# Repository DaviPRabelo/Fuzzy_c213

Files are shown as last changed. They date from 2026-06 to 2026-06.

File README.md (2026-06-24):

<div align="center">

# Câmara Térmica — Controle Fuzzy

Controle de temperatura de uma câmara térmica por **lógica fuzzy (Mamdani)**,
com visualização em tempo real por um dashboard web via **MQTT**.







`C213 · Sistemas Embarcados · Inatel`

</div>

---

## Sumário

- [Arquitetura](#arquitetura)
- [Convenção de sinais](#convenção-de-sinais)
- [Estrutura de arquivos](#estrutura-de-arquivos)
- [Como rodar o controlador](#como-rodar-o-controlador)
- [Como abrir o dashboard](#como-abrir-o-dashboard)
- [Comunicação MQTT](#comunicação-mqtt)
- [Limitações conhecidas](#limitações-conhecidas)

## Integrantes

| Nome | Matrícula |
|---|---:|
| DAVÍ PADULA RABELO | 1917 |
| KAUÃ VICTOR GARCIA SIÉCOLA | 1887 |
| MATHEUS RENÓ TORRES | 1954 |
---

## Arquitetura

```mermaid
flowchart LR
    DASH["Dashboard<br/>(browser)"]
    BROKER(["Broker MQTT · HiveMQ"])
    ESP["ESP32 · controle fuzzy<br/>(pendente)"]
    PLANT["Aquecedor / Cooler<br/>+ sensor de temperatura"]

    DASH -->|setpoint| BROKER
    BROKER -->|setpoint| ESP
    ESP -->|telemetria JSON| BROKER
    BROKER -->|telemetria| DASH
    ESP -->|PWM| PLANT
    PLANT -->|temperatura| ESP

    classDef pending stroke-dasharray:5 5,fill:#fff7ed,stroke:#fb923c,color:#9a3412;
    class ESP pending;
```

O sistema tem três peças conceituais:

| Peça | Arquivo | Papel |
|---|---|---|
| Projeto do controlador | `fuzzy.py` | Define pertinências + 25 regras, valida e gera gráficos (roda no PC, **offline**) |
| Interface | `dashboard.html` | Mostra temperatura/setpoint/erro/ação em tempo real e envia o setpoint |
| Controle embarcado | *(pendente)* | Firmware do ESP32 que lê o sensor, roda o fuzzy, aciona PWM e publica MQTT |

> O `fuzzy.py` é uma ferramenta **offline**: projeta o controlador, imprime testes de
> sinal e gera os gráficos das pertinências e da superfície de controle.

---

## Convenção de sinais

Toda a lógica segue uma convenção única, consistente entre o `.py` e o dashboard:

| Grandeza | Definição | Interpretação |
|---|---|---|
| **erro** | `e = SP − T` | `e > 0` → está **frio** (T abaixo do setpoint) |
| **Δe** (delta_erro) | variação do erro entre amostras | tendência (esfriando / esquentando) |
| **u** (ação) | saída de controle em % | **`u > 0` → aquecer** · **`u < 0` → resfriar** |

Termos linguísticos: `NG` (negativo grande) … `ZE` (zero) … `PG` (positivo grande)
para as entradas; `RF` (resfriar forte) … `MA` (manter) … `AF` (aquecer forte) para a saída.

---

## Estrutura de arquivos

```
fuzzy_codigo/
├── fuzzy.py            # controlador fuzzy + geração de gráficos (offline)
├── dashboard.html      # painel web em tempo real (MQTT + Chart.js)
├── requirements.txt    # dependências Python
├── pertinencias.png    # gráfico das funções de pertinência (gerado pelo .py)
├── superficie.png      # superfície de controle 3D (gerado pelo .py)
└── README.md
```

---

## Como rodar o controlador

O controlador vive em `fuzzy.py`.

1. Crie um ambiente virtual e instale as dependências:

   ```bash
   python -m venv .venv
   # Windows
   .venv\Scripts\activate
   # Linux/macOS
   source .venv/bin/activate

   python -m pip install -r requirements.txt
   ```

2. Execute:

   ```bash
   python fuzzy.py
   ```

   O script imprime três testes de sinal e gera os dois gráficos:

   | Saída | O que mostra |
   |-------|--------------|
   | `pertinencias.png` | As funções de pertinência de **erro**, **Δe** e **ação** |
   | `superficie.png` | A **superfície de controle** 3D `u = f(erro, Δe)` |

---

## Como abrir o dashboard

O dashboard vive em `dashboard.html`.

> [!TIP]
> Sirva o arquivo por HTTP — alguns navegadores bloqueiam WebSocket a partir de `file://`.

```bash
python -m http.server 8080
# depois abra  http://localhost:8080/dashboard.html
```

O indicador de status mostra:

- 🔴 **Desconectado** — sem conexão com o broker (tenta reconectar a cada 3 s);
- 🟢 **Conectado** — recebendo telemetria normalmente;
- 🟡 **Conectado · sem dados** — conexão ativa, mas sem telemetria há mais de 8 s
  (ESP32 parou de publicar / sinal perdido).

Os botões de setpoint (35 / 50 / 65 °C) publicam o novo SP no broker.

### Painel "Inferência Fuzzy"

O dashboard reimplementa o controlador Mamdani em JavaScript (mesmas funções de
pertinência e as 25 regras de `fuzzy.py`) e mostra, em tempo real, o passo a
passo da inferência a cada amostra:

1. **Fuzzificação** — funções de pertinência de `erro` e `Δe` com o valor atual marcado
   e os termos ativos destacados;
2. **Base de regras** — a matriz 5×5; a célula destacada (com anel) é a regra dominante
   no instante, tingida pela intensidade de ativação μ;
3. **Defuzzificação** — o conjunto de saída agregado, o **centroide** e, em seguida, o
   **comando** após o ganho de saída `Ku` e a saturação em ±100 % (ver abaixo),
   atualizados junto com a telemetria.

### Saída do atuador (ganho Ku + saturação)

O centroide do conjunto agregado nunca alcança as bordas do universo — mesmo com `RF`/`AF`
totalmente ativados ele satura em ≈ ±79 %. Por isso o controlador aplica a estrutura padrão
**núcleo fuzzy → ganho de saída `Ku` ≈ 1,27 → saturação em ±100 %**, usando toda a faixa
física do atuador (`u>0` aquece, `u<0` resfria). O painel de defuzzificação mostra as duas
grandezas: o `centroide` (tracejado) e o `comando` final (linha cheia).

---

## Comunicação MQTT

| Item | Valor |
|---|---|
| Broker | `broker.hivemq.com` |
| Porta | `8000` (WebSocket) |
| Tópico de telemetria | `inatel/c213/camara/dados` — **ESP32 → dashboard** (JSON) |
| Tópico de setpoint | `inatel/c213/camara/setpoint` — **dashboard → ESP32** (número como texto, `retained`) |

**Formato do JSON em `inatel/c213/camara/dados`:**

```json
{ "temp": 31.4, "sp": 50, "erro": 18.6, "u": 73 }
```

| Campo | Tipo | Descrição |
|---|---|---|
| `temp` | número | temperatura medida (°C) |
| `sp` | número | setpoint atual (°C) |
| `erro` | número | `e = sp − temp` (°C) |
| `u` | número | ação de controle em % (`u>0` aquece, `u<0` resfria) |
| `de` | número *(opcional)* | variação do erro Δe; se ausente, o dashboard a deriva de amostras sucessivas |

O dashboard tolera campos ausentes e ignora payloads com JSON inválido ou campos
mal-tipados (validação numérica em cada campo).

---

## Limitações conhecidas

- **Broker público sem isolamento:** `broker.hivemq.com` é compartilhado e sem
  autenticação/TLS; os tópicos são fixos. Para uso em laboratório, prefira WSS
  (porta 8884) e prefixe os tópicos com um identificador único da equipe.

---

<div align="center">
<sub>C213 · Sistemas Embarcados · Inatel</sub>
</div>

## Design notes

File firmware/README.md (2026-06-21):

# Thermal Chamber Fuzzy ESP32

Firmware PlatformIO para controle fuzzy de uma câmara térmica usando ESP32, sensor BMP180 e ventoinha/exaustor acionado por PWM.

## Hardware considerado

- ESP32 comum (`board = esp32dev`)
- BMP180 via I2C
- Ventoinha acionada por PWM via transistor/MOSFET externo
- MQTT para setpoint e telemetria

## Pinagem

| Função | GPIO |
|---|---:|
| SDA BMP180 | GPIO5 |
| SCL BMP180 | GPIO4 |
| PWM ventoinha | GPIO2 |

Observação: GPIO2 é pino de strapping no ESP32. Funciona como PWM, mas o circuito externo não deve forçar nível indevido durante o boot.

## Tópicos MQTT

### Setpoint

```text
thermal_chamber/c3_01/setpoint
```

Payload aceito:

```json
45.0
```

ou:

```json
{"setpoint": 45.0}
```

### Telemetria

```text
thermal_chamber/c3_01/telemetry
```

Exemplo:

```json
{
  "device_id": "thermal-chamber-esp32-01",
  "temp_c": 47.35,
  "setpoint_c": 45.00,
  "error_c": 2.35,
  "delta_error_c": 0.18,
  "pwm_pct": 72.0,
  "sensor_ok": true,
  "safety_mode": false,
  "uptime_ms": 123456
}
```

### Status

```text
thermal_chamber/c3_01/status
```

## Configuração de rede

Copie:

```bash
cp include/secrets.example.h include/secrets.h
```

Edite `include/secrets.h` com sua rede Wi-Fi e broker MQTT.

Se `include/secrets.h` não existir, o projeto usa `secrets.example.h` apenas para permitir compilação inicial.

## Comandos

Compilar:

```bash
pio run -e esp32
```

Gravar:

```bash
pio run -e esp32 -t upload
```

Monitor serial:

```bash
pio device monitor
```

Testes do controlador fuzzy no PC:

```bash
pio test -e native
```

## Controle

O erro foi definido como:

```text
erro = temperatura_medida - setpoint
```

Assim, quando a temperatura está acima do setpoint, o erro é positivo e a ventoinha deve aumentar a exaustão.

Como o soprador térmico não é controlado pelo ESP32, a saída fuzzy controla apenas a capacidade de resfriamento/exaustão.

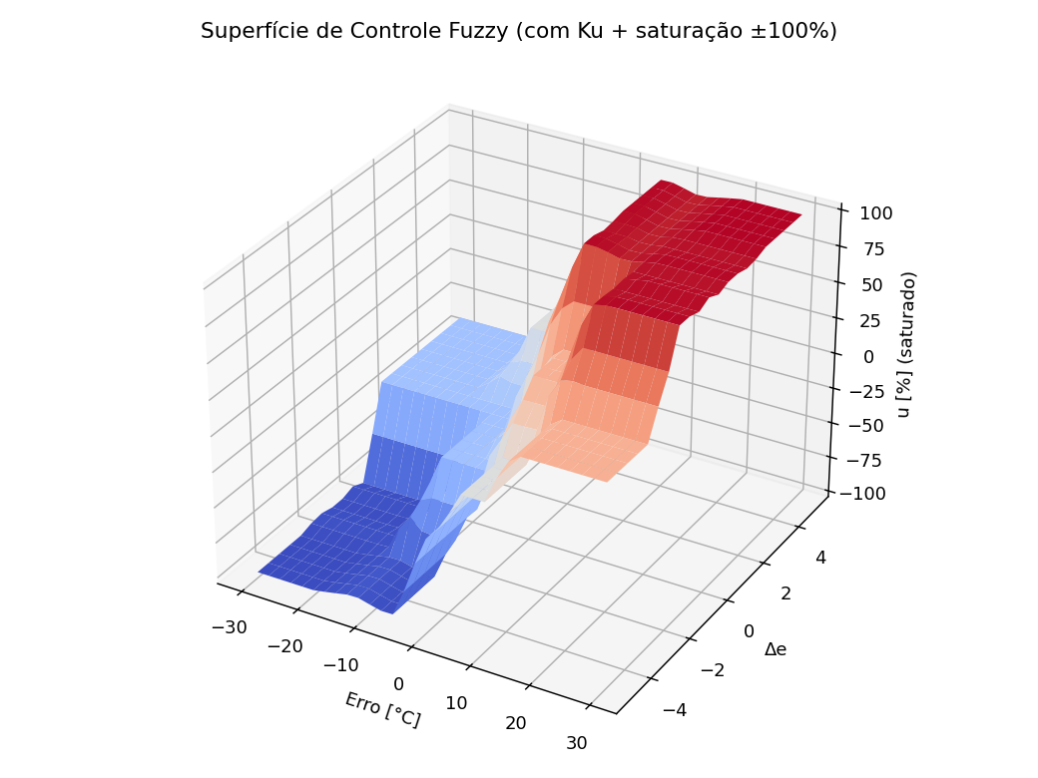
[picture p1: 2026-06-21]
superficie.png

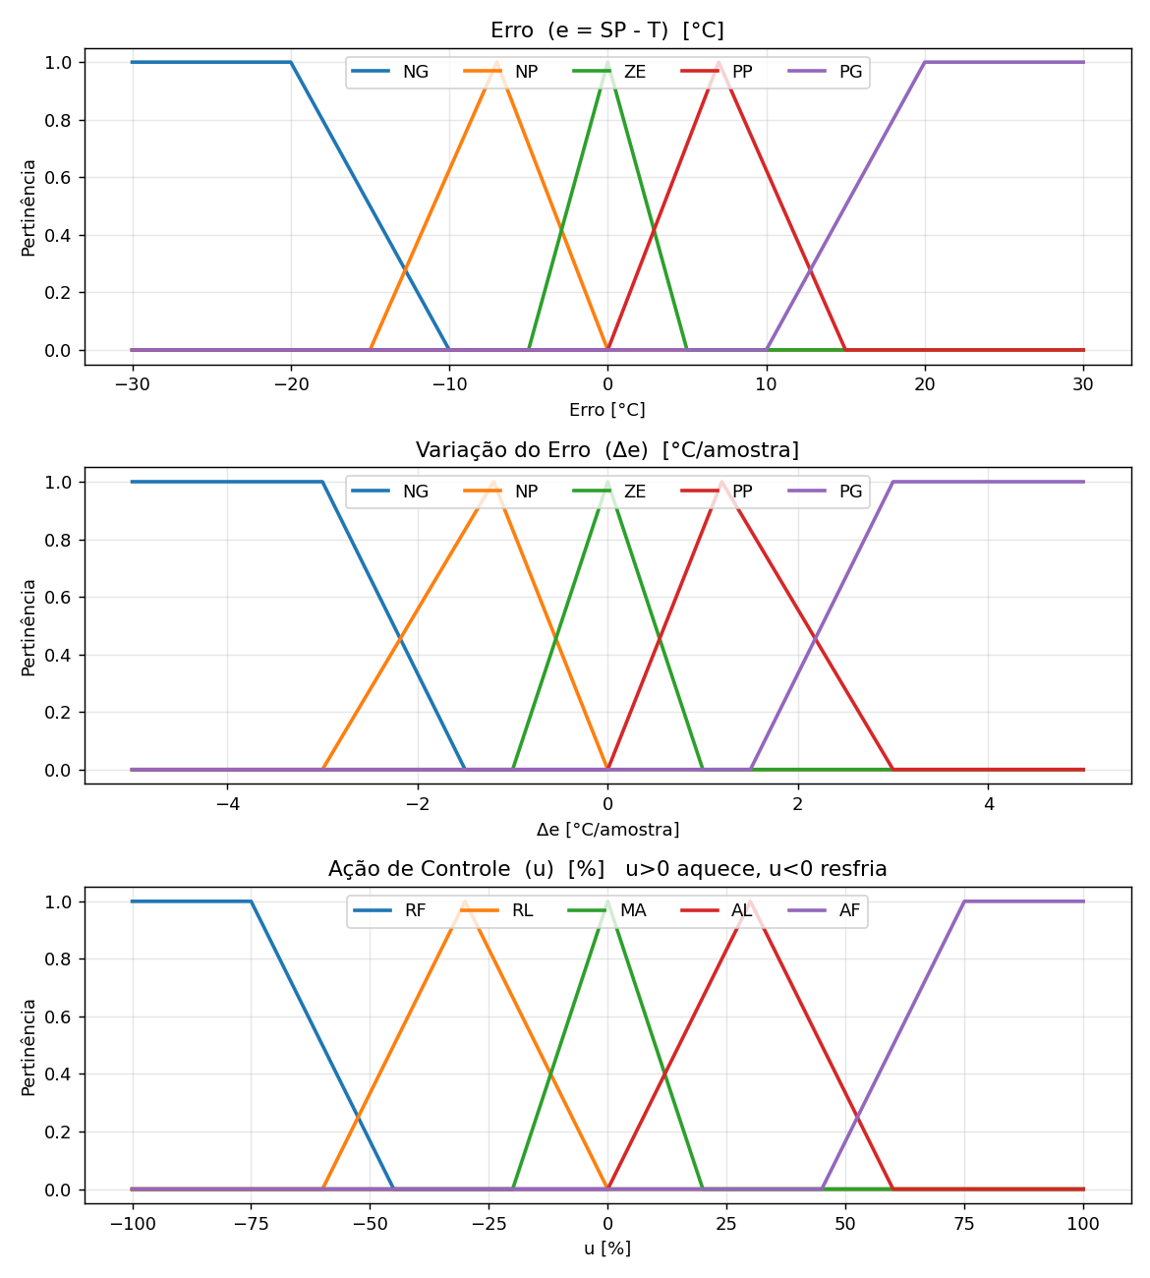
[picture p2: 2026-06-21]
pertinencias.png

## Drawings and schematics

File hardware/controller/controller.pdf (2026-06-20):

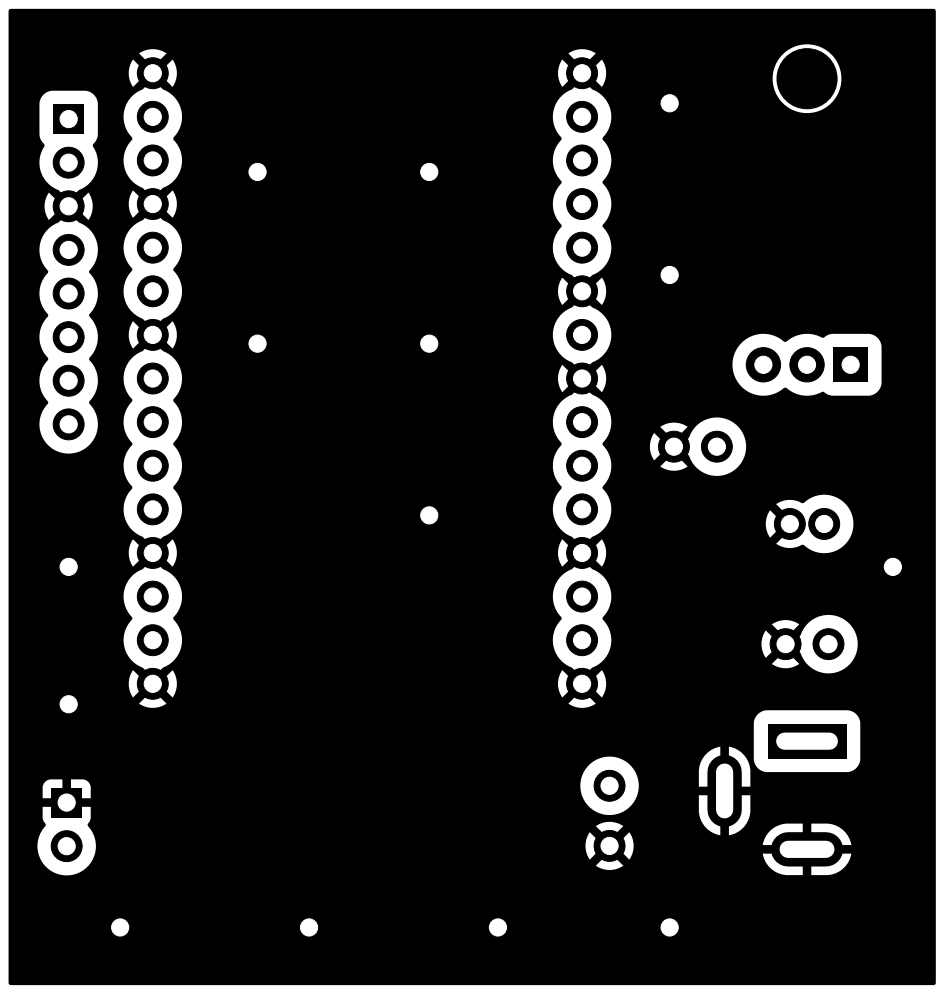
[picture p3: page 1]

Size: A4 | Rev:
KiCad E.D.A. 10.0.3 | Id: 1/2

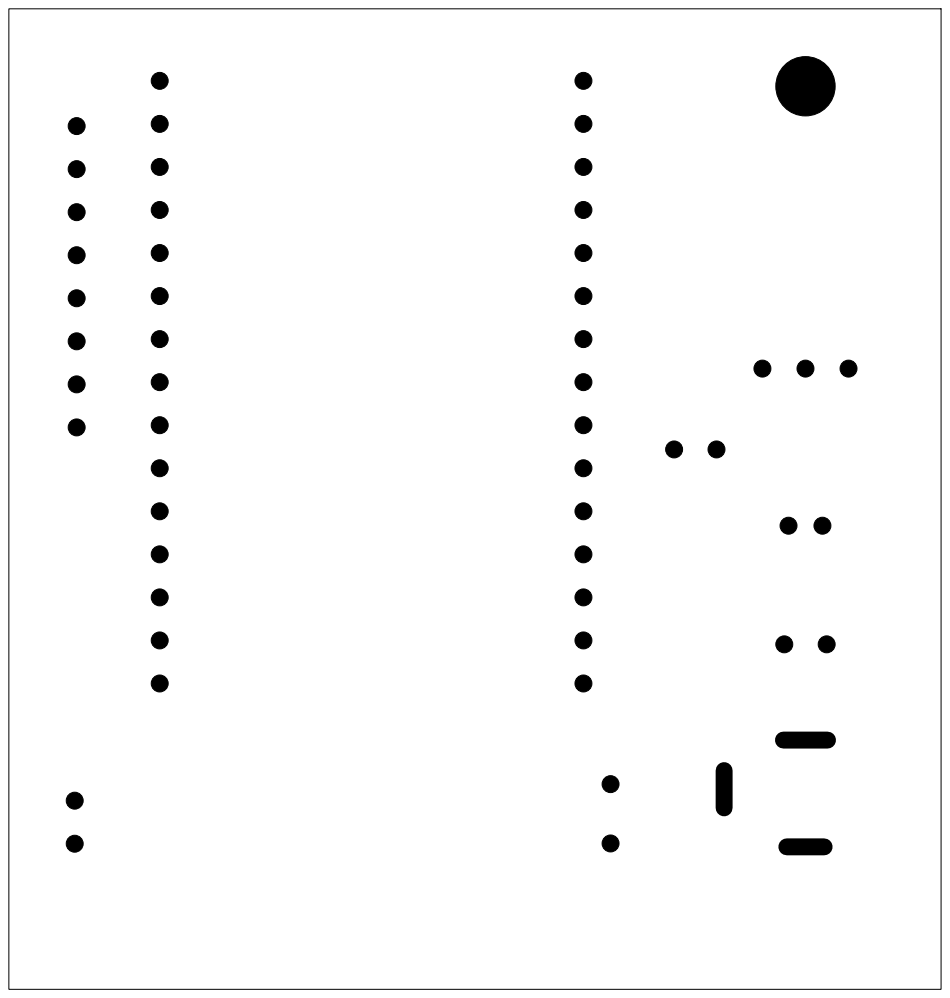
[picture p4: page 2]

Size: A4 | Rev:
KiCad E.D.A. 10.0.3 | Id: 2/2

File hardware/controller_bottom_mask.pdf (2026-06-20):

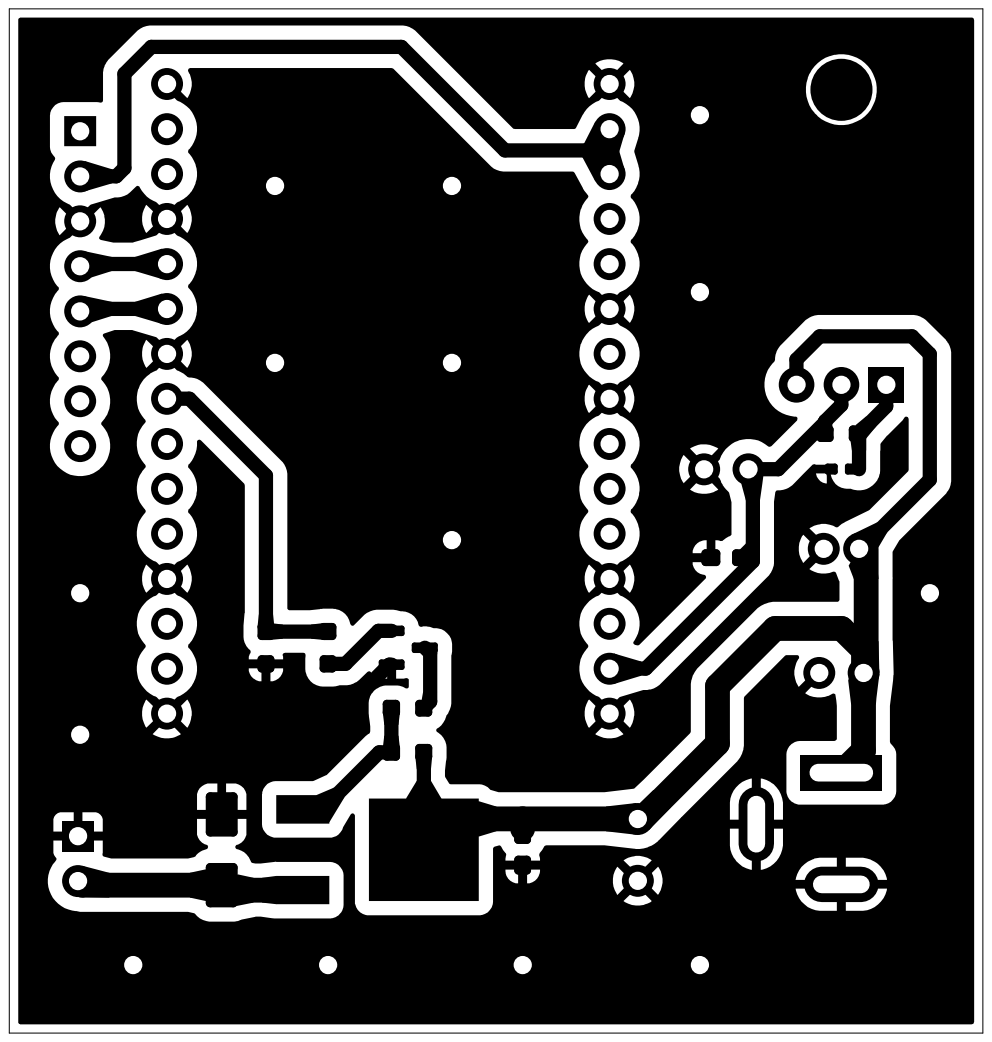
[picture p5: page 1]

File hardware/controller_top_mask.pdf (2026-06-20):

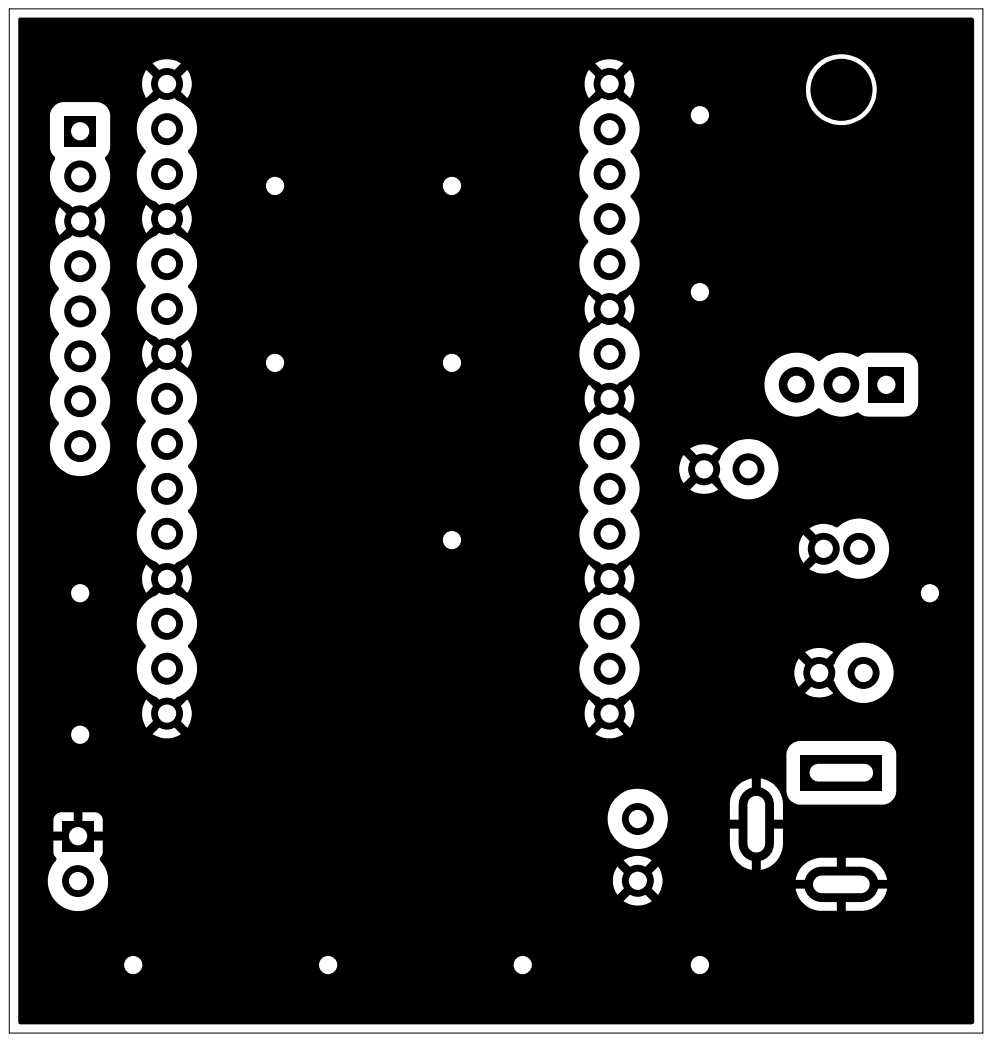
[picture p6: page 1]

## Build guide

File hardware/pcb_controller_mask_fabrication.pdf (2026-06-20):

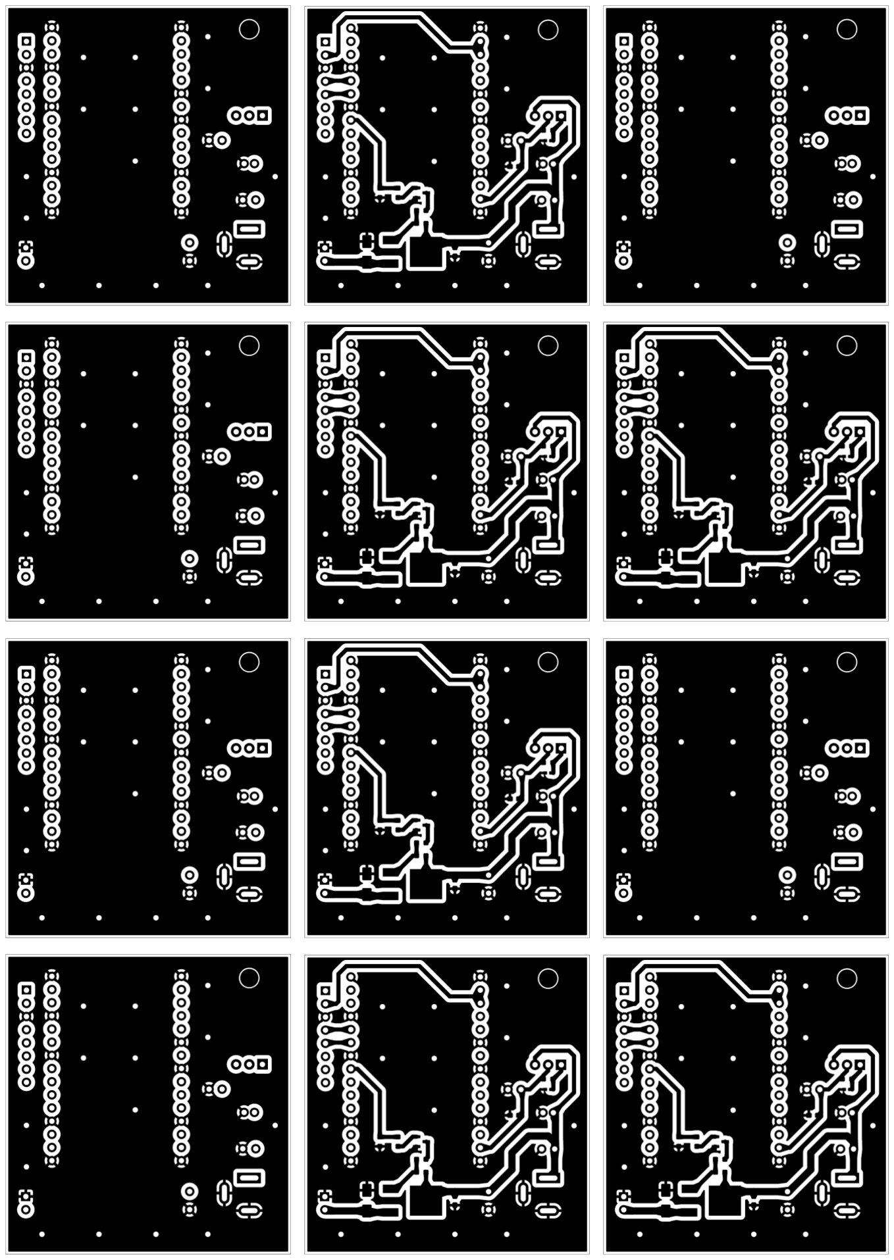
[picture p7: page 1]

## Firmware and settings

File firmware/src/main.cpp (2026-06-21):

#include <Arduino.h>
#include <Wire.h>
#include <cmath>

#include "app_config.h"
#include "pins.h"
#include "bmp180_sensor.h"
#include "fan_pwm.h"
#include "fuzzy_controller.h"
#include "wifi_service.h"
#include "mqtt_service.h"
#include "control_types.h"

namespace
{
    Bmp180TemperatureSensor temperatureSensor;
    FanPwm fan;
    FuzzyController fuzzyController;

    float setpointC = AppConfig::DEFAULT_SETPOINT_C;

    float lastTemperatureC = NAN;
    float lastErrorC = 0.0f;
    float lastDeltaErrorC = 0.0f;
    float lastPwmDutyPercent = 0.0f;

    bool lastSensorOk = false;
    bool safetyMode = false;

    uint8_t consecutiveSensorFailures = 0;

    uint32_t lastControlUpdateMs = 0;
    uint32_t lastTelemetryMs = 0;

    float rateLimit(float target, float current, float maxStep)
    {
        if (target > current + maxStep)
        {
            return current + maxStep;
        }

        if (target < current - maxStep)
        {
            return current - maxStep;
        }

        return target;
    }

    void onSetpointReceived(float candidateSetpointC)
    {
        if (!std::isfinite(candidateSetpointC))
        {
            MqttService::publishStatus("setpoint_rejected_not_finite");
            return;
        }

        if (
            candidateSetpointC < AppConfig::SETPOINT_MIN_C ||
            candidateSetpointC > AppConfig::SETPOINT_MAX_C
        )
        {
            MqttService::publishStatus("setpoint_rejected_out_of_range");
            return;
        }

        setpointC = candidateSetpointC;

        Serial.print("Novo setpoint recebido: ");
        Serial.print(setpointC);
        Serial.println(" C");

        MqttService::publishStatus("setpoint_updated");
    }

    void updateControlLoop()
    {
        float measuredTemperatureC = NAN;
        const bool sensorOk = temperatureSensor.readTemperatureC(measuredTemperatureC);

        lastSensorOk = sensorOk;

        if (!sensorOk)
        {
            ++consecutiveSensorFailures;

            if (consecutiveSensorFailures >= AppConfig::SENSOR_MAX_CONSECUTIVE_FAILURES)
            {
                safetyMode = true;
                lastPwmDutyPercent = AppConfig::FAN_MAX_DUTY_PERCENT;
                fan.setDutyPercent(lastPwmDutyPercent);
                MqttService::publishStatus("sensor_failure_fan_forced_max");
            }

            return;
        }

        consecutiveSensorFailures = 0;
        lastTemperatureC = measuredTemperatureC;

        const float errorC = measuredTemperatureC - setpointC;
        const float deltaErrorC = errorC - lastErrorC;

        float requestedPwmPercent = fuzzyController.computeDutyPercent(errorC, deltaErrorC);

        safetyMode = false;

        if (measuredTemperatureC >= AppConfig::TEMP_CRITICAL_C)
        {
            safetyMode = true;
            requestedPwmPercent = AppConfig::FAN_MAX_DUTY_PERCENT;
        }

        float limitedPwmPercent = requestedPwmPercent;

        if (!safetyMode)
        {
            limitedPwmPercent = rateLimit(
                requestedPwmPercent,
                lastPwmDutyPercent,
                AppConfig::MAX_PWM_STEP_PERCENT
            );
        }

        fan.setDutyPercent(limitedPwmPercent);

        lastErrorC = errorC;
        lastDeltaErrorC = deltaErrorC;
        lastPwmDutyPercent = fan.dutyPercent();

        Serial.print("T=");
        Serial.print(measuredTemperatureC, 2);
        Serial.print(" C | SP=");
        Serial.print(setpointC, 2);
        Serial.print(" C | e=");
        Serial.print(errorC, 2);
        Serial.print(" C | de=");
        Serial.print(deltaErrorC, 2);
        Serial.print(" C | PWM=");
        Serial.print(lastPwmDutyPercent, 1);
        Serial.println(" %");
    }

    void publishTelemetry()
    {
        TelemetryData telemetry;

        telemetry.temperatureC = lastTemperatureC;
        telemetry.setpointC = setpointC;
        telemetry.errorC = lastErrorC;
        telemetry.deltaErrorC = lastDeltaErrorC;
        telemetry.pwmDutyPercent = lastPwmDutyPercent;
        telemetry.sensorOk = lastSensorOk;
        telemetry.safetyMode = safetyMode;
        telemetry.uptimeMs = millis();

        MqttService::publishTelemetry(telemetry);
    }
}

void setup()
{
    Serial.begin(AppConfig::SERIAL_BAUDRATE);
    delay(500);

    Serial.println();
    Serial.println("Inicializando camara termica fuzzy - ESP32");

    Wire.begin(Pins::I2C_SDA, Pins::I2C_SCL);

    if (!temperatureSensor.begin())
    {
        Serial.println("Falha ao inicializar BMP180. Ventoinha sera acionada em seguranca.");
        safetyMode = true;
    }
    else
    {
        Serial.print("Sensor inicializado: ");
        Serial.println(temperatureSensor.name());
    }

    if (!fan.begin())
    {
        Serial.println("Falha ao inicializar PWM da ventoinha.");
    }

    if (safetyMode)
    {
        fan.setDutyPercent(AppConfig::FAN_MAX_DUTY_PERCENT);
    }

    WifiService::begin();
    MqttService::begin(onSetpointReceived);

    lastControlUpdateMs = millis();
    lastTelemetryMs = millis();
}

void loop()
{
    WifiService::loop();
    MqttService::loop();

    const uint32_t now = millis();

    if (now - lastControlUpdateMs >= AppConfig::CONTROL_PERIOD_MS)
    {
        lastControlUpdateMs = now;
        updateControlLoop();
    }

    if (now - lastTelemetryMs >= AppConfig::TELEMETRY_PERIOD_MS)
    {
        lastTelemetryMs = now;
        publishTelemetry();
    }
}

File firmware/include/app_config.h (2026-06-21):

#pragma once

#include <stdint.h>

#if __has_include("secrets.h")
#include "secrets.h"
#else
#include "secrets.example.h"
#endif

namespace AppConfig
{
    constexpr const char* DEVICE_ID = "thermal-chamber-esp32-01";

    constexpr uint32_t SERIAL_BAUDRATE = 115200;

    constexpr uint32_t CONTROL_PERIOD_MS = 1000;
    constexpr uint32_t TELEMETRY_PERIOD_MS = 2000;
    constexpr uint32_t WIFI_RECONNECT_PERIOD_MS = 5000;
    constexpr uint32_t MQTT_RECONNECT_PERIOD_MS = 5000;

    constexpr float DEFAULT_SETPOINT_C = 45.0f;
    constexpr float SETPOINT_MIN_C = 25.0f;
    constexpr float SETPOINT_MAX_C = 80.0f;

    constexpr float TEMP_SENSOR_MIN_C = -40.0f;
    constexpr float TEMP_SENSOR_MAX_C = 85.0f;
    constexpr float TEMP_CRITICAL_C = 84.0f;

    constexpr uint8_t SENSOR_MAX_CONSECUTIVE_FAILURES = 3;

    constexpr uint32_t PWM_FREQUENCY_HZ = 25000;
    constexpr uint8_t PWM_RESOLUTION_BITS = 10;
    constexpr uint8_t PWM_CHANNEL = 0;

    constexpr float FAN_OFF_THRESHOLD_PERCENT = 3.0f;
    constexpr float FAN_MIN_EFFECTIVE_DUTY_PERCENT = 20.0f;
    constexpr float FAN_MAX_DUTY_PERCENT = 100.0f;

    constexpr float MAX_PWM_STEP_PERCENT = 12.0f;
}

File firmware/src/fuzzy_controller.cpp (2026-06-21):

#include "fuzzy_controller.h"

#include <algorithm>
#include <cmath>

namespace
{
    enum ErrorSet : unsigned int
    {
        ERROR_NEG_BIG = 0,
        ERROR_NEG_SMALL,
        ERROR_ZERO,
        ERROR_POS_SMALL,
        ERROR_POS_BIG,
        ERROR_COUNT
    };

    enum DeltaErrorSet : unsigned int
    {
        DELTA_FALLING = 0,
        DELTA_STABLE,
        DELTA_RISING,
        DELTA_COUNT
    };

    enum OutputSet : unsigned int
    {
        OUT_OFF = 0,
        OUT_LOW,
        OUT_MEDIUM,
        OUT_HIGH,
        OUT_MAX,
        OUT_COUNT
    };

    constexpr OutputSet RULES[ERROR_COUNT][DELTA_COUNT] =
    {
        // Delta erro:  caindo        estavel       subindo
        /* e NG */    { OUT_OFF,     OUT_OFF,      OUT_LOW    },
        /* e NP */    { OUT_OFF,     OUT_LOW,      OUT_MEDIUM },
        /* e ZE */    { OUT_LOW,     OUT_MEDIUM,   OUT_HIGH   },
        /* e PP */    { OUT_MEDIUM,  OUT_HIGH,     OUT_MAX    },
        /* e PG */    { OUT_HIGH,    OUT_MAX,      OUT_MAX    }
    };
}

float FuzzyController::trapmf(float x, float a, float b, float c, float d)
{
    if (a == b && x <= b)
    {
        return 1.0f;
    }

    if (c == d && x >= c)
    {
        return 1.0f;
    }

    if (x <= a || x >= d)
    {
        return 0.0f;
    }

    if (x >= b && x <= c)
    {
        return 1.0f;
    }

    if (x > a && x < b)
    {
        return (x - a) / (b - a);
    }

    if (x > c && x < d)
    {
        return (d - x) / (d - c);
    }

    return 0.0f;
}

float FuzzyController::membershipError(unsigned int setIndex, float errorC)
{
    switch (setIndex)
    {
        case ERROR_NEG_BIG:
            return trapmf(errorC, -30.0f, -30.0f, -15.0f, -5.0f);

        case ERROR_NEG_SMALL:
            return trapmf(errorC, -15.0f, -6.0f, -2.0f, 0.0f);

        case ERROR_ZERO:
            return trapmf(errorC, -1.5f, -0.4f, 0.4f, 1.5f);

        case ERROR_POS_SMALL:
            return trapmf(errorC, 0.0f, 2.0f, 6.0f, 15.0f);

        case ERROR_POS_BIG:
            return trapmf(errorC, 5.0f, 15.0f, 30.0f, 30.0f);

        default:
            return 0.0f;
    }
}

float FuzzyController::membershipDeltaError(unsigned int setIndex, float deltaErrorC)
{
    switch (setIndex)
    {
        case DELTA_FALLING:
            return trapmf(deltaErrorC, -3.0f, -3.0f, -1.0f, -0.15f);

        case DELTA_STABLE:
            return trapmf(deltaErrorC, -0.5f, -0.1f, 0.1f, 0.5f);

        case DELTA_RISING:
            return trapmf(deltaErrorC, 0.15f, 1.0f, 3.0f, 3.0f);

        default:
            return 0.0f;
    }
}

float FuzzyController::membershipOutput(unsigned int setIndex, float pwmPercent)
{
    switch (setIndex)
    {
        case OUT_OFF:
            return trapmf(pwmPercent, 0.0f, 0.0f, 0.0f, 8.0f);

        case OUT_LOW:
            return trapmf(pwmPercent, 5.0f, 15.0f, 25.0f, 40.0f);

        case OUT_MEDIUM:
            return trapmf(pwmPercent, 30.0f, 45.0f, 55.0f, 70.0f);

        case OUT_HIGH:
            return trapmf(pwmPercent, 60.0f, 75.0f, 85.0f, 95.0f);

        case OUT_MAX:
            return trapmf(pwmPercent, 85.0f, 95.0f, 100.0f, 100.0f);

        default:
            return 0.0f;
    }
}

float FuzzyController::computeDutyPercent(float errorC, float deltaErrorC) const
{
    float numerator = 0.0f;
    float denominator = 0.0f;

    for (int pwm = 0; pwm <= 100; ++pwm)
    {
        float aggregatedMembership = 0.0f;

        for (unsigned int e = 0; e < ERROR_COUNT; ++e)
        {
            const float muError = membershipError(e, errorC);

            for (unsigned int de = 0; de < DELTA_COUNT; ++de)
            {
                const float muDelta = membershipDeltaError(de, deltaErrorC);
                const float ruleStrength = std::min(muError, muDelta);

                if (ruleStrength <= 0.0f)
                {
                    continue;
                }

                const OutputSet outputSet = RULES[e][de];
                const float muOutput = membershipOutput(outputSet, static_cast<float>(pwm));
                const float clippedOutput = std::min(ruleStrength, muOutput);

                aggregatedMembership = std::max(aggregatedMembership, clippedOutput);
            }
        }

        numerator += static_cast<float>(pwm) * aggregatedMembership;
        denominator += aggregatedMembership;
    }

    if (denominator <= 0.0001f)
    {
        return 0.0f;
    }

    return numerator / denominator;
}

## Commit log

2026-06-19 (feature): add hardware schematic
    [controller.kicad_pcb, controller.kicad_sch]
2026-06-20 (frature): add pcb controller
    [controller.kicad_pcb, controller.kicad_sch]
2026-06-21 (feature): add firmware ESP32
2026-06-22 fix: aponta MQTT para test.mosquitto.org e corrige encoding
